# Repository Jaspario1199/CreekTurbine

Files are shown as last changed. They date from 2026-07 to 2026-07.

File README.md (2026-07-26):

# CreekTurbine 🌊⚡

A DIY **hydrokinetic** turbine you can drop into a creek — an "underwater wind
turbine" that harvests the *kinetic* energy of the moving stream to trickle-charge
a battery. No dam, no vertical drop, removable before floods.

> **Status: Mk1 DESIGN FROZEN — [docs/SPEC.md](docs/SPEC.md).** Every design
> decision is locked with rationale; the **complete unit is CAD-modeled** (14
> parametric parts + a positioned 28-part assembly, `cad/step/_assembly.step`);
> the physics engine (115 tests), verified rotor research, 19-finding red-team
> audit, and bench/field test protocol are all in. Next milestone: the wet
> prototype ([docs/TEST_PROTOCOL.md](docs/TEST_PROTOCOL.md)).

```bash
pip install -r requirements.txt
python -m scripts.measure_creek        # how to measure your creek (float method)
python -m scripts.size_turbine --figs  # size the turbine + render figures to ./output
python -m pytest                       # 46 checks on the physics
```

---

## Read this first: a creek is a *trickle-charger*, not a generator set

The power in moving water is `P = ½·ρ·A·v³`. That **v³** is the whole story:
double the water speed and you get **8×** the power. Two creeks that look the same
to your eye can differ 8× in what they'll make. So:

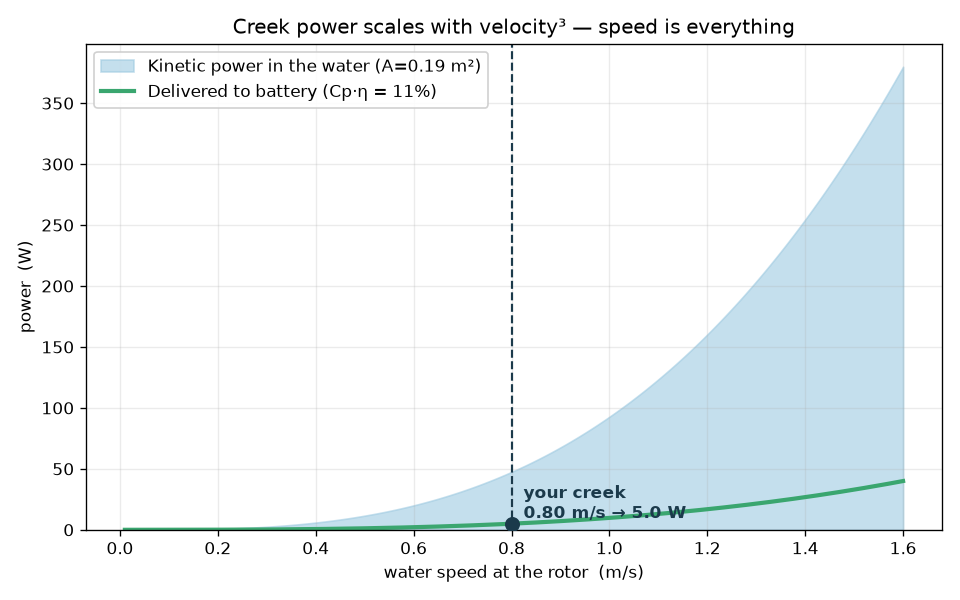
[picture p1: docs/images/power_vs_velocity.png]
Creek power scales with velocity cubed


- **Measure your creek's speed honestly** — it dominates everything else.
- A gentle 0.5 m/s creek yields a few watts; a brisk 1 m/s creek, tens of watts.
- **A few watts, 24/7, is genuinely useful.** 5 W around the clock ≈ **90 Wh/day**
  — enough to keep phones, trail/security cameras, LED lights, and IoT sensors
  alive indefinitely (a ~10 W always-on Wi-Fi router or a laptop needs a bit more
  creek). It is **not** going to run a fridge or a house.

The toolkit's job is to tell you the truth for *your* water before you spend a
dollar — and to show you the two free levers that beat buying bigger gear:
**measure the fastest spot**, and **speed the water up** with a chute or shroud
(since power ∝ v³, a 1.2× speed-up is a ~1.7× power gain).

---

## What it tells you (real output for the default creek)

`python -m scripts.size_turbine` on the placeholder creek (0.8 m/s, 1.5 m × 0.5 m
channel, 5 W target):

```
 TARGET: 5.0 W continuous at the battery
   → Savonius rotor: Ø 0.34 m × 0.54 m tall  (frontal area 0.19 m²)
   Blocks 25% of the wetted channel — comfortable.
   At 0.80 m/s: shaft ≈ 40 rpm, torque ≈ 2.0 N·m, mechanical ≈ 8.5 W → battery ≈ 5.0 W
 GENERATOR MATCH (the part people get wrong):
   Rotor turns ~40 rpm — that's SLOW. For a 12 V bus to cut in at your low-season
   ~0.48 m/s, pick a PMA with Ke ≈ 0.5 V/rpm (≈ 2 rpm/V).
 ENERGY: 5.0 W × 24 h × 75% uptime ≈ 90 Wh/day  (33 kWh/year)
 BATTERY: 19 Ah at 12 V (LiFePO4) for 2 days autonomy
 WHAT IT RUNS:  ✓ phone  ✓ security cam  ✓ LED light  ✓ sensors  ✗ Wi-Fi  ✗ laptop  ✗ fridge
```

It also renders these:

| Size vs. velocity | Daily energy budget | Recommended rotor |
|---|---|---|
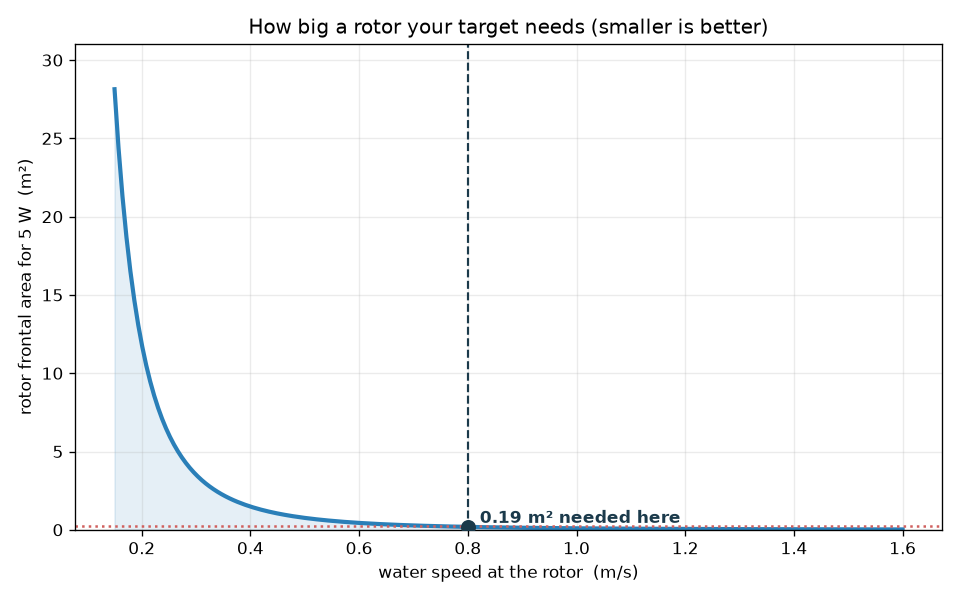
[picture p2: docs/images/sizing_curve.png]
sizing
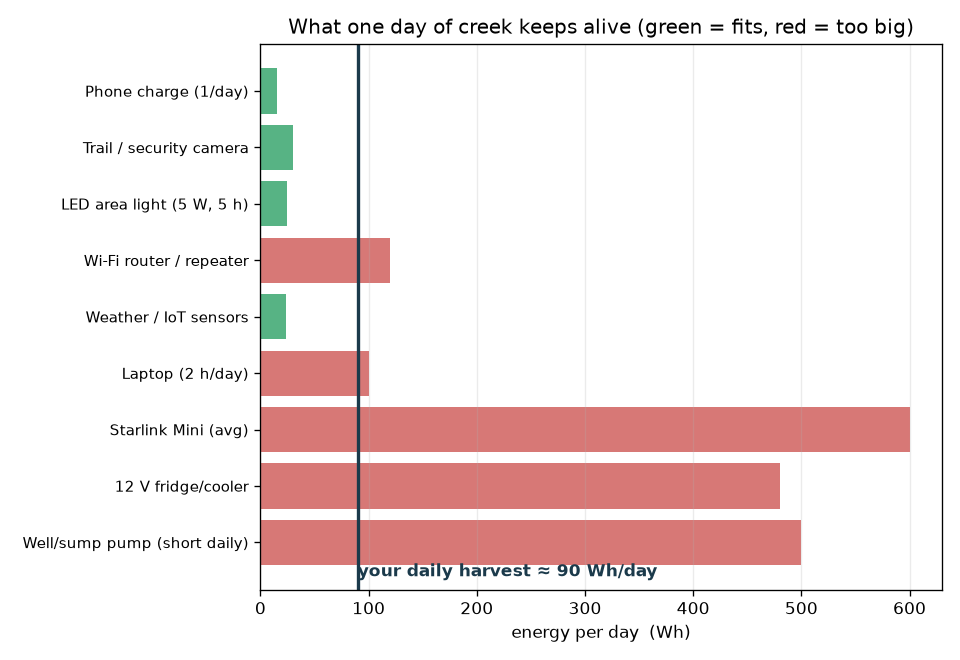
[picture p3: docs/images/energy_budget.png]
energy
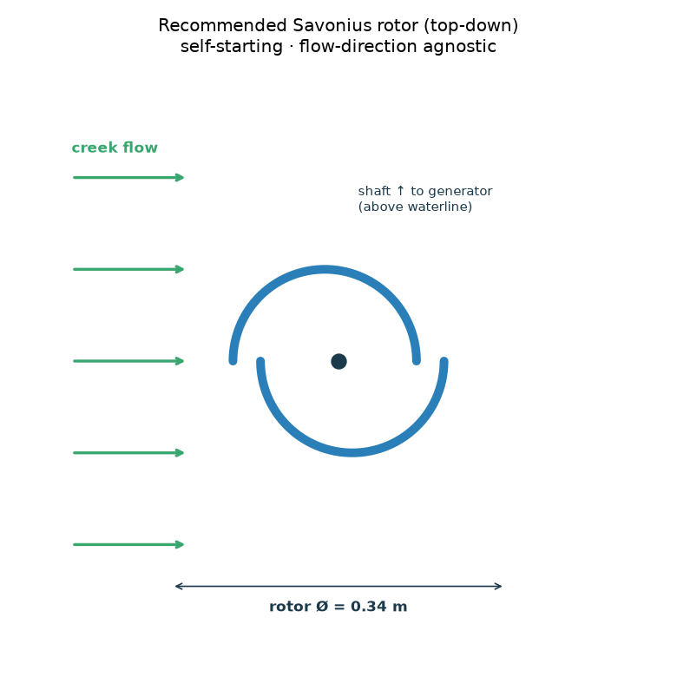
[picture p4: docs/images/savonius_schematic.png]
savonius
|  |  |  |

---

## Why a Savonius (vertical-axis) turbine

The default design is a **Savonius** — a vertical-axis drag rotor (think two
scoops making an S). Its power coefficient isn't the best (a propeller wins on
paper), but it's the best *system* for a real DIY creek:

- **Self-starts in slow water**, where a propeller just stalls.
- **Doesn't care which way the flow points** — creeks meander and eddy.
- **Vertical shaft ⇒ the generator sits on top, above the water.** This turns the
  single hardest problem — keeping a generator dry — into "bolt it to a plate in
  the air." Only the bearings get wet.
- **Debris-tolerant, low-rpm/high-torque, buildable from a barrel or PVC pipe.**

The costs — a bigger rotor per watt and a slow shaft that needs careful generator
matching — are shown explicitly, never hidden. Got a brisk, deep creek? Set
`TURBINE_TYPE = "axial"` and the model sizes the higher-efficiency propeller
instead. Details in **[docs/ARCHITECTURE.md](docs/ARCHITECTURE.md)**.

### Want an enclosed underwater box with a dry generator inside?

Yes — that's a *ducted turbine with a dry nacelle*, and it's modeled in
`ducted.py` / `scripts/box_turbine.py`. The honest punchline: a box around a
purely *kinetic* rotor gains little (a creek's speed is worth only ~3 cm of
head), **but building in a small elevation drop turns it into a low-head turbine
worth ~30× more** for the same opening. Cross the wet/dry wall with a **magnetic
coupling** (no shaft seal to leak), and mind that a submerged air box is very
buoyant. Full write-up: **[docs/BOX_AND_DUCT.md](docs/BOX_AND_DUCT.md)**.

### Want to carry it to any creek (camping / backyard)?

That's a **portable power station** — a sealed drop-in turbine, a *low-voltage DC*
cable to shore (never mains AC in the water), and a battery-buffered box on dry
land. The battery is the trick: loads run off it while the turbine tops it up, so
you get smooth, instant power and it works **24/7 — at night and in rain, unlike
solar**. A multi-input controller lets the same battery also charge from solar or
a wall outlet (your "switch between sources"). Modeled in `portable.py` /
`scripts/portable.py`; full write-up: **[docs/PORTABLE.md](docs/PORTABLE.md)**.

### Or fully self-contained — one box with a handle you set in the creek?

The cleanest form, and the vertical-axis design makes it natural: **one housing,
rotor at the bottom (wet), battery + generator + outlets stacked above the
waterline (dry), handle on top.** Set it in the stream and the outlets are live —
no cable, plug-and-play. The real catch is *stability* (a free-standing box in
current wants to slide/tip, so its base needs weight or a stake), which the model
sizes. Modeled in `selfcontained.py` / `scripts/self_contained.py`; full write-up:
**[docs/SELF_CONTAINED.md](docs/SELF_CONTAINED.md)**.

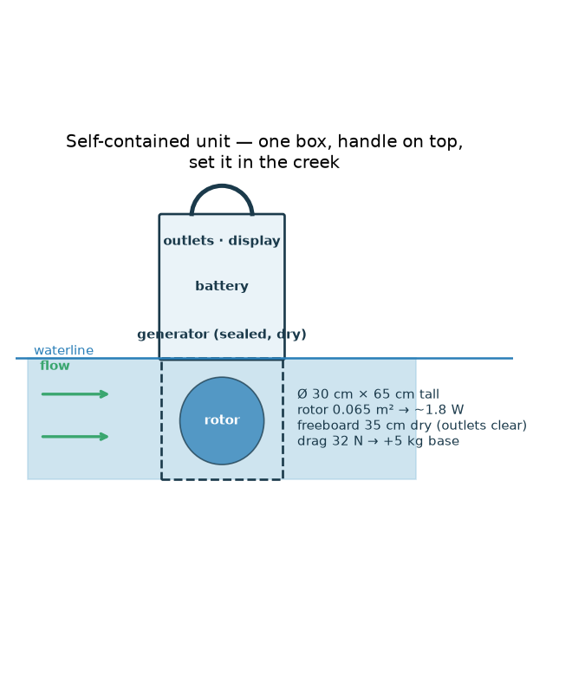
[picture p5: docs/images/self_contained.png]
Self-contained unit


### Want the highest-Cp rotor that still survives the creek?

A cited literature pass (**[docs/RESEARCH_ROTORS.md](docs/RESEARCH_ROTORS.md)**)
found the sweet spot: an **optimized/hydrofoil, helical Savonius**. Verified
results — a cambered-hydrofoil blade nearly **doubles Cp** (~0.26 vs ~0.13 at
0.4 m/s), and arc-angle/overlap/aspect + end-plate tuning reaches ~0.19 — while
keeping the blunt, self-starting, debris-shedding toughness a lift rotor throws
away. Selectable in `config.py` (`SAVONIUS_PROFILE = "conventional" | "optimized"
| "hydrofoil"`), and there's a printable **helical blade** in `cad/`.

---

## How it works (the modules)

1. **`hydrokinetics.py`** — the physics you must trust: `½·ρ·A·v³`, the Betz limit
   (16/27), rotor sizing, rpm/torque, flow-augmentation. Tested against
   hand-computed values.
2. **`rotor.py`** — Savonius & axial rotors behind one interface; turns a power
   target into rotor dimensions.
3. **`generator.py`** — the part people get wrong: **cut-in velocity** (below which
   you make *nothing*) and a Ke recommender to match your low-season flow.
4. **`energy.py`** — daily/annual Wh, battery Ah sizing, and the "what it runs" table.
5. **`siting.py`** — float-method + cross-section math to measure your creek.
6. **`simulator.py`** — renders all of it to PNGs (headless).
7. **`ducted.py`** — the "enclosed underwater air box" / ducted low-head turbine:
   flow-through-a-throat, the huge payoff of building in a little *head*, and how
   much ballast a submerged air box needs. See **[docs/BOX_AND_DUCT.md](docs/BOX_AND_DUCT.md)**.
8. **`portable.py`** — the carry-anywhere **power-station** build: battery-buffer
   runtime (sustained vs. burst), the waterproof low-voltage-DC cable to shore
   (volt-drop & gauge), and pack weight. See **[docs/PORTABLE.md](docs/PORTABLE.md)**.
9. **`selfcontained.py`** — the all-in-one "box with a handle": rotor-fits-box +
   freeboard geometry, and the drag/sliding/tipping math that sizes the base so
   the current can't move it. See **[docs/SELF_CONTAINED.md](docs/SELF_CONTAINED.md)**.

---

## Repository layout

```
creekturbine/
  config.py          # ← the ONLY file you edit: your creek, your goal, your battery
  hydrokinetics.py   # ½·ρ·A·v³, Betz, sizing, rpm/torque, augmentation
  rotor.py           # Savonius + axial rotor models (one interface)
  generator.py       # PMA cut-in velocity + Ke matching (the classic failure point)
  energy.py          # daily/annual energy, battery sizing, what-it-runs
  siting.py          # measure-your-creek math (float method, cross-section)
  ducted.py          # enclosed-box / ducted low-head turbine + buoyancy/ballast
  portable.py        # carry-anywhere power station: battery buffer, cable, weight
  selfcontained.py   # all-in-one "box with a handle": fit, freeboard, drag/tipping
  magnetics.py       # sealed magnetic coupling: torque model + sizing
  funnel.py          # converging-intake funnel: continuity + critical-velocity cap
  simulator.py       # renders the figures (matplotlib, headless)
scripts/
  measure_creek.py   # walk through measuring velocity & flow
  size_turbine.py    # end-to-end sizing report (+ --figs)
  box_turbine.py     # model the enclosed underwater air-box idea
  portable.py        # model the portable power-station build
  self_contained.py  # model the all-in-one box unit (+ --figs)
  mag_coupling.py    # size the sealed magnetic coupling to the rotor torque
  funnel.py          # model a converging chute for a mellow/shallow creek
  demo_sim.py        # render the whole picture book to ./output
cad/
  params.py          # ONE dimensional chain (mm): rotor -> plates -> housing -> skid
  parts/             # THE COMPLETE UNIT, 14 parametric parts: helical blade
                     #   (segmented printable), grooved end plates, mag-coupling
                     #   discs + magnet cover, bulkhead, cage rings, dry housing,
                     #   lid+handle, skid/ballast base, funnel wings, trash rack,
                     #   shaft coupler, generator mount
  export_all.py      # -> cad/step/*.step + cad/stl/*.stl (all 14)
tests/               # 46 checks on the physics/energy/generator/siting math
docs/
  ARCHITECTURE.md    # how the pieces fit + design decisions
  SITING.md          # measure first, then make the water faster (+ permits)
  BOX_AND_DUCT.md    # the enclosed underwater air-box idea, costed (dry generator + head)
  FUNNEL.md          # converging chute to make a mellow/shallow creek useful
  PORTABLE.md        # carry-anywhere power station (cable, battery, source-switching)
  SELF_CONTAINED.md  # all-in-one "box with a handle" set-in-the-creek unit
  RESEARCH_ROTORS.md # cited survey: high-Cp + durable rotor geometries (+ comparison table)
  MAG_COUPLING.md    # sealed magnetic coupling — the no-leak wet→dry crossing
  ASSEMBLY.md        # full build order stitching every part + subsystem together
  CRITIQUE.md        # the red-team audit: 19 findings, each fixed/documented/tracked
  TEST_PROTOCOL.md   # bench + field tests (B1–B5, F1–F4) that calibrate the model
  SAFETY.md          # water + electricity + a spinning rotor: read this
  HARDWARE.md        # BOM + the generator problem (cut-in, low rpm)
  ROADMAP.md         # phase-by-phase build plan
  RESEARCH.md        # the physics & why the default coefficients
```

---

## Where this is going

| Phase | What | Cost |
|---|---|---|
| **0** ✅ | Physics/sizing engine, rotor+generator+energy models, simulator, tests, CAD | Free |
| **1** | Measure your creek (2+ seasons), lock rotor size & generator Ke | ~$0 |
| **2** | Bench-build rotor + generator, prove **cut-in** and charging | 💰 generator + battery |
| **3** | Wet install: frame, anchoring, trash rack, **dump load**, sealed electronics | 💰 ~$250–450 |
| **4** | Flow augmentation (chute/shroud) + flood/winter survival | 💰 iteration |

The genuinely hard, risky parts are called out honestly: **matching a generator
to a slow shaft**, **keeping it dry and alive in a creek**, and the **legal/
environmental** rules you must settle *before* building. See
**[docs/ROADMAP.md](docs/ROADMAP.md)**.

**Ready to build?** [docs/ASSEMBLY.md](docs/ASSEMBLY.md) is the full,
phase-by-phase build order — plan in software → print/buy parts → rotor →
sealed drivetrain → dry electronics → housing/intake → bench test → wet install.
The **complete unit is CAD-modeled** (14 parametric parts on one dimensional
chain — see [cad/README.md](cad/README.md)):

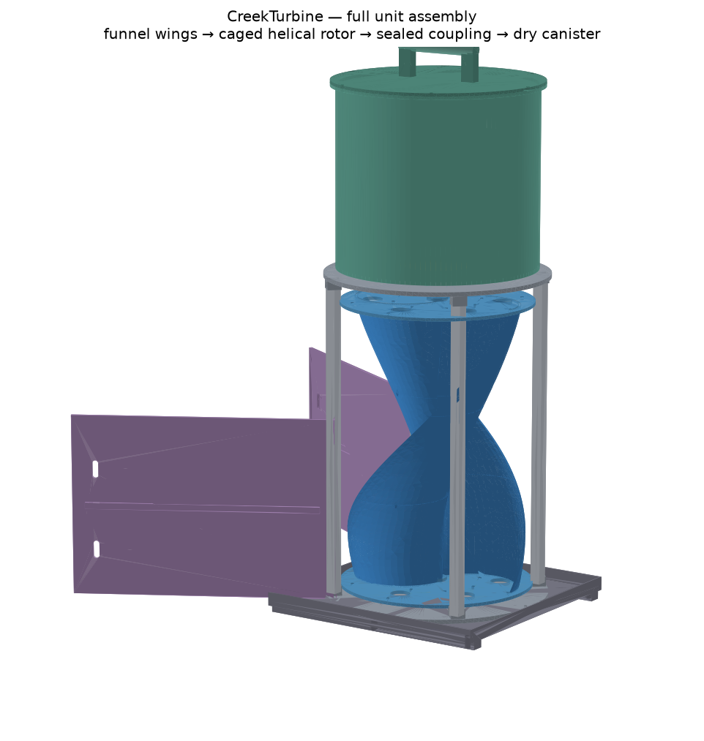
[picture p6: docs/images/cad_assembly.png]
Full unit assembly


> ⚠️ **Before you build, read [docs/SAFETY.md](docs/SAFETY.md).** A hydro source
> runs 24/7 and can't be switched off like a solar panel — it *needs* a charge
> controller with a dump load, a fused battery, and sealed, elevated electronics.
> And check your **water rights and fish-passage rules** first
> ([docs/SITING.md](docs/SITING.md)).

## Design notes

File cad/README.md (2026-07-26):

# CAD — the printed & cut structure

**The complete unit is modeled** — every physical piece of the machine, on one
parametric dimensional chain (blade → end plate → housing bore → cage → skid),
so changing `ROTOR_DIA`/`ROTOR_HEIGHT` re-derives everything:

Full unit assembly

**Base assembly model:** `python -m cad.assembly` exports the positioned 28-part
assembly — **`cad/step/_assembly.step`** (named parts; open in FreeCAD, Fusion,
Onshape, any STEP viewer) and `cad/stl/_assembly.stl` (single mesh). Bought
items (columns, shaft, generator, battery) are included as labeled solids.

The Savonius rotor's **scoops** are cut from cheap PVC pipe or sheet (not
printed). What's parametric here is the **structure that holds them and carries
the shaft up to the dry generator**:

| Part | What it is | Print notes |
|---|---|---|
| `end_plate` | Top & bottom discs with **profile-matched grooves** that seat the blade ends (a twisted edge can't take a bolt — it drops into its groove and is epoxied; bolt rings become clamping/through-rod holes). Print **2** identical; clock the top one to the blade twist at assembly. | PETG, 4+ walls, 40%+ infill. At Ø370 mm it exceeds most beds — **cut from HDPE sheet/plywood using the STEP as a template** for full-size rotors; print only small ones. Overhangs the scoops on purpose (raises Cp). |
| `savonius_blade` | Helical Savonius scoop — **one printable SEGMENT** (a full blade exceeds every consumer printer's Z). Print **`SCOOP_COUNT × BLADE_SEGMENTS`** copies (default 2×3); segments are identical — stack each rotated by `BLADE_SEG_TWIST`, register on 3 mm pins (filament) in the end-face holes, epoxy the joints. | PETG/ASA, 4+ walls; print upright. Twist = `BLADE_TWIST_DEG`; set 0 for straight. `BLADE_SEGMENTS` auto-computes from `PRINTER_MAX_Z`. |
| `shaft_coupler` | Joins the rotor shaft to the generator shaft; radial set screws. | Print solid-ish (PETG/ABS/nylon), or buy a metal coupler and use this as the fit reference. |
| `mag_coupling_disc` | Magnetic-coupling disc — ring of magnet pockets + shaft hub. Print **2** (wet + dry). Seals the wet→dry crossing with no shaft seal. | PETG; press magnets in alternating polarity. Seal/pot the wet disc's magnets. See [MAG_COUPLING.md](../docs/MAG_COUPLING.md). |
| `bulkhead` | The sealed wall the coupling drives through: thin center membrane + bolted, O-ring-grooved rim. | **Don't print it** — it's a flat disc: **cut from 3 mm PC/acrylic/FR4 sheet** using the STEP as a drill template. **NON-MAGNETIC only** — never plain steel. |
| `trash_rack` | Barred intake screen that sheds debris (the #1 field failure). Print **1+**. | PETG/ASA; angle it downstream-leaning. Size open area via `siting.screen_*`. |
| `generator_mount` | Top plate the PMA bolts to, standing above the waterline on legs. | PETG, 5+ walls. |
| `cage_ring_top` | Top of the open wet cage: sockets the 4 columns, carries the shared 8-bolt clamp circle (cage → bulkhead → housing floor in one stack). Print **1**. | PETG/ASA, 5+ walls. |
| `cage_ring_bottom` | Cage base disc: column sockets, raised lower-bearing boss (silt has to climb), drain holes, skid bolt circle. Print **1**. | PETG/ASA. Bearing seat = `BEARING_OD` flanged stainless. |
| *(cage columns)* | **BUY, don't print**: 4 × 20 mm aluminium square tube cut to `CAGE_COL_LEN` — stiffer and cheaper than any print, and a 600 mm part fits no bed. | Hacksaw + deburr; clamp screws hold them. |
| `housing_upper` | The dry canister: sealed floor (bulkhead clamps under it), shell, lid flange, outlet-panel cutout. Print in sections **or roll from HDPE/PVC pipe** (STEP = cut/drill template). | Ø384 — pipe/sheet at full size. |
| `lid_handle` | Gasketed lid + the carry handle (takes the unit's full weight — thick bar, wide posts). Print **1**. | PETG/ASA, high infill in the posts. |
| `skid_base` | Skid + ballast tray: sacrificial runners underneath (cut from UHMW ideally), perimeter ballast tray, cage bolts, corner stake + tether holes. | Runners = replaceable wear parts. |
| `funnel_wing` | Converging-intake wing wall (make **2**, one flipped): mounting flange to a cage column, mid-height rib, stake slots. | **Cut from 6 mm HDPE sheet** at full size (STEP = template); print for small units. |
| `magnet_cover` | Thin bonded cover disc sealing the WET coupling disc's potted magnets — the marine barrier, not a glue dab. Print **1** (or cut from 1 mm PC). | Bond in wet epoxy over the potted face. |

Load-bearing, permanently-wet parts — the **shaft, fasteners, bearings** — are
**metal (stainless)**, never printed.

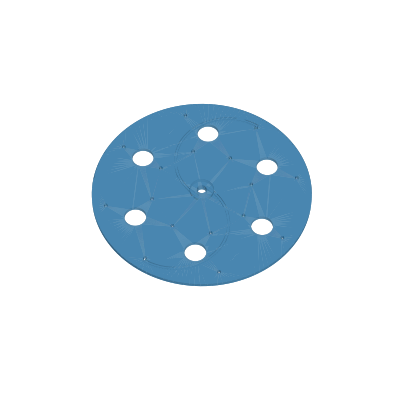
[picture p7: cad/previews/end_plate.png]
end plate
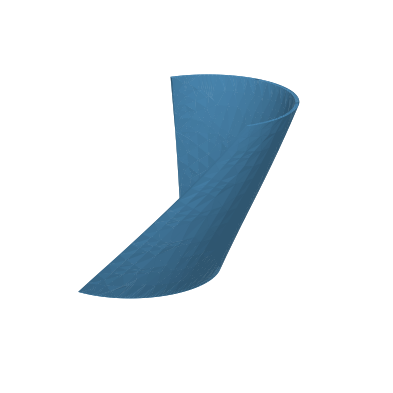
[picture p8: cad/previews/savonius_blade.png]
helical blade
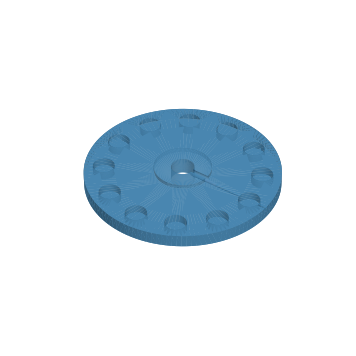
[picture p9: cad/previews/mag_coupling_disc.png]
mag coupling disc
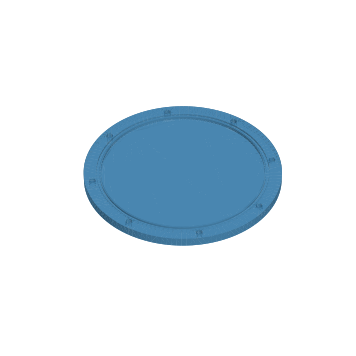
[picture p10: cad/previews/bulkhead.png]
bulkhead
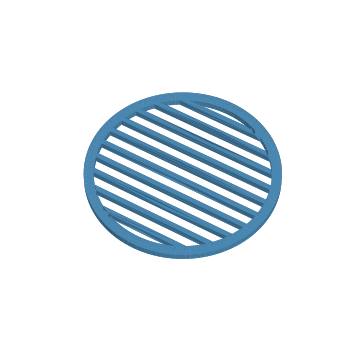
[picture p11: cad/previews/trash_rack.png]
trash rack
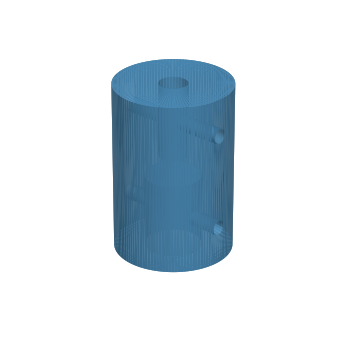
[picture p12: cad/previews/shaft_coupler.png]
shaft coupler
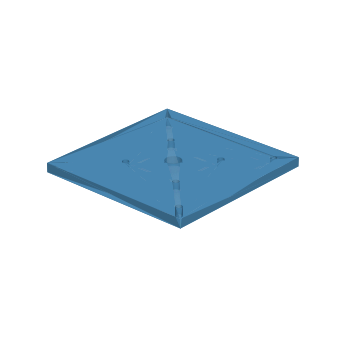
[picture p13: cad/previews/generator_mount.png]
generator mount
      

## Regenerating

```bash
pip install -r requirements-cad.txt        # heavy: pulls OpenCascade
# 1. edit cad/params.py — especially SHAFT_DIA, GEN_SHAFT_DIA, GEN_BODY_DIA,
#    GEN_BOLT_CIRCLE to match the parts you actually buy, and ROTOR_DIA /
#    ROTOR_HEIGHT to match `python -m scripts.size_turbine`
python -m cad.export_all                   # writes cad/step/*.step + cad/stl/*.stl
```

The committed STEP/STL match the defaults in `cad/params.py` (which mirror the
recommended rotor from the default `config.py`). **Always sanity-check the mesh
in your slicer before printing** — the bolt patterns are a sensible starting
point, not a guarantee they line up with your specific scoop pipe.

## Printing for water

- **PETG** is the sweet spot: cheap, tough, low water absorption, UV-OK for a
  season. **ASA/ABS** if you want better UV life. Avoid bare **PLA** underwater
  — it creeps and slowly hydrolyzes.
- Print **watertight**: 4–6 perimeters, 30–50% infill, and consider a wipe of
  epoxy on the end plates for a multi-season part.
- Anything structural underwater should really be **metal**; treat printed parts
  as brackets and jigs, not the primary wet load path.

### Scuff- / abrasion-resistant outer shell

The housing drags on gravel and takes rock knocks, so the **outer** wants to be
tougher than a printed wall:

- **Best: HDPE or UHMW-PE** — a cut plastic barrel, sheet, or machined block. It's
  what kayaks and cutting boards are made of: extremely scuff/abrasion resistant,
  tough, near-zero water absorption. (Trade-off: hard to 3D-print or glue — bolt
  and gasket it instead.)
- **Printed alternative: ASA** (UV + impact) or **PCTG / PETG-CF**, with a thick
  wall — then add a rugged skin: a **truck bed-liner coating** (e.g. roll-on
  polyurethane) sprayed over the shell resists scuffs well.
- **Sacrificial bottom skid + corner bumpers:** a bolt-on **UHMW skid plate** on
  the base and **TPU bumpers** on the corners take the abuse and are cheap to
  replace. This is the highest-value scuff protection for the least effort.

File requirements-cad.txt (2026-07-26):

# CAD: regenerate the printed parts (STEP/STL) from the parametric scripts.
# Heavier install (pulls OpenCascade via cadquery-ocp). Only needed if you edit
# cad/params.py and want to re-export.
cadquery>=2.4

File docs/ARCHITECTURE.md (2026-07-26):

# Architecture — how the pieces fit

CreekTurbine is a small, honest engineering toolkit. Everything is driven from
**one file you edit** (`creekturbine/config.py`) and computed from there, so you
can answer "is this worth building for MY creek?" before spending a dollar.

## The energy chain (and where power is lost)

```
  creek flow                                                    your loads
  (v, depth) ──► ROTOR ──► SHAFT ──► GENERATOR ──► RECTIFIER ──► CHARGE ──► BATTERY ──► USB / 12V
                 (Cp)      (bearings) (PMA, η)     (3-phase)     CONTROLLER   (store)     / inverter
                  │          │          │                          │
             capture at    torque    volts ∝ rpm               MPPT/PWM +
             most Betz     & rpm      (cut-in!)                 DUMP LOAD
             (16/27)                                           (overspeed safety)
```

Each stage is a module:

| Stage | Module | The one thing it tells you |
|---|---|---|
| Resource | `hydrokinetics.py` | how much power is in the water (`½·ρ·A·v³`) and the Betz ceiling |
| Rotor | `rotor.py` | Savonius vs axial geometry, Cp, and the rotor **size** to hit a target |
| Shaft | `hydrokinetics.py` | rpm & torque from velocity + TSR (this is what the generator sees) |
| Generator | `generator.py` | the **cut-in velocity** below which you make nothing, and how to match Ke |
| Storage | `energy.py` | daily/annual Wh, battery Ah, and **what it actually runs** |
| Siting | `siting.py` | how to *measure* v and A honestly (float method, cross-section) |
| Picture | `simulator.py` | renders all of the above to PNGs |

## Design decisions (and why)

**Hydrokinetic, not "dam-and-drop."** A creek is a low-head, flowing resource.
Building a dam to make head is a permitting/ecological nightmare and usually
illegal on a natural creek. We harvest the *kinetic* energy of the moving
water — an "underwater wind turbine." No dam, removable, low impact.

**Vertical-axis Savonius is the default.** Not because its Cp is best (it
isn't — a propeller wins there), but because it's the best *system* for a DIY
creek:

- **Self-starting in slow water** (drag-driven), where a propeller stalls.
- **Flow-direction agnostic** — creeks meander and back-eddy; it doesn't care.
- **Vertical shaft ⇒ the generator lives on top, above the water.** This turns
  the single hardest problem (keeping a generator dry) into "bolt it to a plate
  in the air." Only bearings get wet.
- **Low rpm, high torque, debris-tolerant, buildable from a barrel/PVC.**

The cost is a bigger rotor for the same watts, and a low shaft rpm that forces
careful generator matching. The toolkit makes both costs explicit instead of
hiding them. If your creek is genuinely brisk and deep, `TURBINE_TYPE = "axial"`
models the higher-Cp propeller alternative.

**Cut-in is a first-class citizen.** The most common DIY failure is a generator
that never reaches charging voltage at creek rpm. `generator.py` computes the
cut-in *velocity* and recommends a Ke so it lands at your creek's **low-season**
flow, not its average.

**One interface for both rotors.** `SavoniusRotor` and `AxialRotor` share the
same `_RotorBase` surface (`frontal_area`, `performance()`, `electrical_power()`),
so everything downstream — sizing, generator matching, energy, the simulator —
works unchanged when you switch types. (Same "one interface, swappable
implementations" trick a good perception stack uses for its detectors.)

## Coordinate & unit conventions

Pure SI throughout the Python (`m`, `m/s`, `W`, `Wh`, `kg`, `rad`); the CAD is
in millimeters (parametric, `cad/params.py`). No hidden globals — every function
takes what it needs and returns a number or a dataclass, which is why the whole
thing is trivially testable (`tests/`, 46 checks against hand-computed values).

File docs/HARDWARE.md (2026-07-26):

# Hardware — bill of materials & the generator problem

Prices are rough 2026 USD for a small (~5–20 W) creek build and will vary. Run
`python -m scripts.size_turbine` first — it tells you the rotor size, the shaft
rpm, and the generator Ke to shop for.

## The one hard part: the generator

Everything else is plumbing; the generator is where builds live or die, for two
reasons the toolkit makes explicit:

1. **Low rpm.** A Savonius turns *tens* of rpm. Most cheap motors are wound to
   make their rated voltage at *thousands* of rpm, so used bare they never
   "cut in" (reach charging voltage) in a creek.
2. **Cut-in.** Below the rpm where the rectified voltage exceeds your battery,
   **zero** current flows. `generator.py` computes the cut-in *velocity*; aim it
   at your creek's **low-season** flow.

Three ways to solve it, cheapest first:

| Option | What | Trade-off |
|---|---|---|
| **Low-Kv PMA** (recommended) | A purpose-made low-rpm permanent-magnet alternator / "PMA" / axial-flux generator (the kind sold for small wind turbines, e.g. rated ~12 V at a few hundred rpm). | Cleanest match; direct-drive a Savonius via the coupler. Costs more than a scrap motor. |
| **Step-up drive** | A common motor + a belt/gear step-up (the report prints the ratio, often ~5–15:1). | Uses cheap parts; adds friction, noise, a wear item, and a few % loss. |
| **Repurposed motor** | A brushed DC motor, a stepper (rectified), a car alternator (no — needs field current & high rpm), or a hoverboard/e-bike hub motor (good: many poles, low Kv). | Free-ish; you must measure its Ke and check cut-in. Hub motors are the best scrap option. |

**Rectifier:** a PMA is 3-phase AC — add a **3-phase bridge rectifier** (six
diodes / a module) to make DC. A brushed DC motor needs only a single diode to
block back-feed.

## Bill of materials

### Rotor & structure
| Item | Notes | ~USD |
|---|---|-----:|
| PVC pipe or HDPE drum for scoops | e.g. a 200 mm PVC pipe cut lengthwise = two scoops; or half a plastic barrel | 10–30 |
| 3D-printed end plates ×2, coupler, gen mount | PETG; print from `cad/` (or cut plywood/HDPE plates) | filament you have |
| **Stainless shaft** (e.g. 16 mm) | permanently wet — must be stainless | 15–30 |
| **Marine/stainless bearings** ×2 (pillow-block) | top can be a plain bearing; keep above silt | 15–35 |
| Stainless bolts/nuts/washers (M5/M6/M8) | scoops, plates, frame | 15–25 |

### Frame & siting
| Item | Notes | ~USD |
|---|---|-----:|
| Frame (galv/stainless unistrut, EMT, or treated lumber) | must survive a flood; make it liftable | 25–60 |
| Anchoring (rebar stakes, ground anchors, sandbags) | to bed AND bank | 15–40 |
| Trash rack / intake screen | angled mesh upstream of the rotor | 10–25 |

### Electrical
| Item | Notes | ~USD |
|---|---|-----:|
| **Low-Kv PMA / hub motor generator** | the heart. REALITY CHECK: buyable PMAs top out ~0.10–0.15 V/rpm — if the report recommends more, use a **boost MPPT** (below) or a belt step-up; don't shop for a unicorn | 40–150 |
| 3-phase bridge rectifier (or Schottky diodes) | AC → DC | 8–20 |
| **BOOST-type MPPT charge controller w/ dump load** | steps a few volts of slow-PMA output UP to the battery — the modern fix for slow-rotor cut-in. Spec **low quiescent draw (<10 mA)**: a 25 mA idler eats 15 %+ of a small harvest, 24/7 | 30–100 |
| **Dump/diversion resistor or heating element** | soaks up power when the battery is full — wired **generator-side, before the BMS** (see SAFETY) | 10–25 |
| **LiFePO4 battery** (12 V, sized by the report, e.g. 20–50 Ah) | BMS **must include low-temperature charge cutoff** (LiFePO4 won't take charge below 0 °C) | 60–180 |
| **Thrust / angular-contact bearings** (pair) | the magnetic coupling's discs pull together with ~300–400 N constantly — plain radial bearings grind flat | 10–30 |
| **12 V → USB-C PD buck module (45–65 W)** | what actually charges the laptop from the battery | 12–30 |
| **Main fuse + holder** at the battery + terminal | the most important safety part | 5–15 |
| Marine tinned wire, gel/heatshrink connectors, sealed enclosure | corrosion is relentless near water | 25–60 |
| (optional) 12 V→USB / small pure-sine inverter | to actually use the power | 15–60 |

**Ballpark:** a minimal ~5–10 W trickle-charger lands around **$250–450**; add
$100–200 for a bigger battery, a nicer MPPT controller, and an inverter.

## Portable ("camping") variant

For a carry-anywhere unit (see [PORTABLE.md](PORTABLE.md)), swap the fixed frame
for a lighter kit and add:

| Item | Notes | ~USD |
|---|---|-----:|
| Compact sealed generator + **magnetic coupling** | no shaft seal to leak; drop-in-any-creek. Magnets: ~24 × Ø15×6 mm N42 NdFeB (two discs) + a thin non-magnetic bulkhead. Size with `scripts.mag_coupling`; see [MAG_COUPLING.md](MAG_COUPLING.md) | 50–120 |
| **Marine tinned DC cable** + **IP68 potted connectors** | the "waterproof extension cord" — low-voltage DC only | 20–60 |
| Portable **LiFePO4 pack** (e.g. 300–500 Wh) | the buffer that gives smooth, instant, 24/7 power | 150–350 |
| **Multi-input charge controller** (turbine + solar + USB-C) | your "switch between sources" | 30–90 |
| Fast anchor kit (stake + guy line / sandbags) | deploy in minutes | 15–35 |
| **Scuff-resistant outer**: HDPE/UHMW shell (or ASA + bed-liner coat) + **UHMW skid plate** + **TPU corner bumpers** | takes gravel drag and rock knocks; skid/bumpers are cheap sacrificial wear parts | 20–70 |

Use a **higher bus voltage (24–48 V)** for anything but the shortest cable run —
it slashes the copper needed and the volt-drop (the model shows ~16× less copper
going 12 V → 48 V). Keep any 120/230 V AC inverter **on land, after the battery**.

## What NOT to do
- **No car alternator** for direct creek drive — it needs field excitation and
  thousands of rpm; it won't cut in.
- **No bare PLA** underwater — it creeps and hydrolyzes. PETG/ASA or metal.
- **Never** run the turbine with no electrical load and no dump — it free-spins
  and destroys itself (and spikes the electronics). See [SAFETY.md](SAFETY.md).

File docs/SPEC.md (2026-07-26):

# CreekTurbine Mk1 — frozen design specification

**Status: DESIGN FROZEN** (rev 1). Every decision below is locked with its
rationale; the short list of parameters *deliberately* left to prototype
calibration is at the end. The complete unit is modeled — open
**`cad/step/_assembly.step`** in any CAD tool for the base model, or regenerate
everything from `cad/params.py` (one dimensional chain).

Full unit assembly

## Identity & envelope

| | |
|---|---|
| Concept | Self-contained hydrokinetic creek turbine — "a box with a handle you set in the stream" |
| Deploys in | any creek **≥ 4 ft wide**, **6 in – 3 ft deep**, mellow flow (~0.4 m/s+) |
| Footprint | skid 460 × 460 mm; funnel wings gather a ~0.9 m swath |
| Height | ~1.02 m (skid → handle) |
| Carry weight | **~15 kg (33 lb) dry** — under the 40 lb budget; ballast is **creek rocks added on-site** into the skid tray, so you never carry it |
| Output | 12 V LiFePO₄ buffer → USB-C PD (laptop), USB, 12 V |
| Performance | ~1.7–4 W continuous (mellow creek, universal funnel): **~1 laptop charge/day in ≥1 ft of water**, derating to ~0.4/day at 6 in. Brisker water or site wing-walls raise it substantially (v³) |

## Frozen decisions (the design record)

| # | Decision | Frozen choice | Why (full rationale linked) |
|---|---|---|---|
| D1 | Energy principle | **Hydrokinetic** (no dam) | legal/eco footprint, removable — [ARCHITECTURE](ARCHITECTURE.md) |
| D2 | Rotor type | **Vertical-axis Savonius** | self-starts in slow water, direction-agnostic, debris-tolerant, vertical shaft puts the generator above water — [RESEARCH_ROTORS](RESEARCH_ROTORS.md) |
| D3 | Blade geometry | **Helical (180° twist), arc-optimized scoop, overlap 0.15, aspect ~1.6, end plates** | verified Cp levers; helix adds self-start smoothness + debris shedding — [RESEARCH_ROTORS](RESEARCH_ROTORS.md) |
| D4 | Sizing basis | **Cp 0.18 (conservative)** for all sizing; optimized geometry's 0.19–0.25 is *margin*, not promise | lab-vs-field honesty — [CRITIQUE #16](CRITIQUE.md) |
| D5 | Rotor size | **Ø 340 × 540 mm** (3 printed segments/blade × 2 blades) | 5 W target at 0.8 m/s; segments fit a 240 mm printer Z — [CRITIQUE #3](CRITIQUE.md) |
| D6 | Blade↔plate joint | **Profile-matched grooves** in the end plates + through-rod clamps + epoxy | a twisted edge can't take a bolt; shared profile source `cad/lib.py` — [CRITIQUE #4](CRITIQUE.md) |
| D7 | Intake | **Universal free-standing funnel**, 0.9 m gather mouth, 0.35 m tall wings | works in any ≥4 ft creek without bank works; speed-up capped honestly at √(g·y) — [FUNNEL](FUNNEL.md) |
| D8 | Wet→dry crossing | **Axial magnetic coupling** (12 × Ø15×6 N42 per disc, R55, 3 mm gap → ~4.2 N·m, slips on overload) through a **cut-from-sheet non-magnetic bulkhead** | no shaft seal to leak; built-in torque limiter — [MAG_COUPLING](MAG_COUPLING.md) |
| D9 | Coupling thrust | **Thrust/angular-contact bearings both shafts** (≥570 N) | ~380 N constant axial pull — [CRITIQUE #2](CRITIQUE.md) |
| D10 | Generator + charge path | Low-Kv PMA → 3-phase rectifier → **boost-MPPT** (low quiescent <10 mA) → 12 V LiFePO₄ (BMS w/ low-temp cutoff) | the *buyable* fix for slow-rotor cut-in — [CRITIQUE #1](CRITIQUE.md) |
| D11 | Overspeed safety | **Dump/clamp on the generator side, before the BMS** + fuse at battery + | BMS disconnect must never orphan the PMA — [SAFETY](SAFETY.md), [CRITIQUE #9](CRITIQUE.md) |
| D12 | Bus voltage | **12 V** | no shore cable in the self-contained form; richest USB/12 V ecosystem ([PORTABLE](PORTABLE.md) covers the 24–48 V cable variant) |
| D13 | Structure | Printed rings/plates (PETG/ASA) + **bought 20 mm Al tube columns** + stainless Ø16 shaft, Ø22 flanged bearings | print what's complex, buy what's long/structural — [cad/README](../cad/README.md) |
| D14 | Outer durability | **HDPE/UHMW shell** (or ASA + bed-liner), **sacrificial UHMW skid runners**, TPU bumpers | scuff resistance with cheap replaceable wear parts |
| D15 | Debris strategy | Blunt drag rotor + **angled trash rack** + open cage + drain holes + raised bearing boss | debris is the #1 field failure — [RESEARCH_ROTORS §4](RESEARCH_ROTORS.md) |
| D16 | Flood strategy | **Retrieval line + pull before storms**; stakes/ballast as backstop (~670 N flood drag computed) | you don't out-anchor a flood — [CRITIQUE #5](CRITIQUE.md) |
| D17 | Loads philosophy | Battery-buffered: loads always run off the pack; turbine trickles it back | smooth output, burst capability, source-agnostic charging |

## Key interfaces (for anyone extending the CAD)

- **Main clamp stack:** cage top ring → bulkhead → housing floor, **8 × M5 on Ø161** — one bolt circle seals and structures the wet/dry joint
- **Shaft:** Ø16 stainless; lower bearing Ø22 flanged in the cage boss; coupling discs bore Ø16 w/ M5 set screws
- **Cage columns:** 4 × 20 mm square tube, 604 mm, socketed ±15 mm with radial M5 clamps
- **Skid bolts:** 4 × M5 on Ø406; stake holes Ø10 at corners
- **Lid:** 6 × M5 on Ø394, gasketed, lip-registered

## Deliberately NOT frozen (calibrate on the prototype — [TEST_PROTOCOL](TEST_PROTOCOL.md))

| Parameter | Current assumption | Calibrated by |
|---|---|---|
| Funnel `confinement` | 0.82 | **F2** float test through the throat |
| Real rotor Cp | 0.18 sizing / 0.19–0.25 geometry | **F3** logged watts |
| Generator Ke & cut-in | catalog value | **B1** drill test |
| Coupling slip torque | ~4.2 N·m (τ·A·R model) | **B2** lever + scale |
| Maintenance interval | unknown | **F4** 72 h soak |

## Cost & verification

- **BOM band:** ~$300–480 ([HARDWARE](HARDWARE.md)) + ~2 kg filament
- **Software verification:** 115 physics/model tests passing; 14 parts + assembly export clean; 19-finding red-team audit closed ([CRITIQUE](CRITIQUE.md))
- **Research basis:** 22 adversarially-verified literature claims ([RESEARCH_ROTORS](RESEARCH_ROTORS.md))

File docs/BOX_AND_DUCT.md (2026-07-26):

# The enclosed underwater box (ducted / low-head turbine)

> "Can I have an enclosed, mostly air-filled box underwater — dry inside — that
> lets water flow in through one part, past a turbine, and out?"

**Yes.** You've described a *ducted turbine with a dry nacelle*, which is how a
lot of real hydro gear is built. This page makes the idea quantitative. Model it
for your creek with:

```bash
python -m scripts.box_turbine --static-head 0.3 --throat 0.05 --air-volume 0.08
```

## The two things a box buys you

1. **A dry generator.** Routing water through only a defined channel lets the
   generator and electronics live in the air-filled part. Keeping the generator
   dry is the single hardest problem in the whole project, so this is a real win.
2. **Flow control / augmentation.** A shaped inlet nozzle + flared outlet
   (diffuser) can pull more flow through the turbine than a bare rotor of the
   same size — the "shrouded / diffuser-augmented" turbine, worth roughly
   1.3–2.5× for a good one. That's the `--diffuser` knob.

## The catch, and the thing that makes it actually worth it

A creek's **speed is worth almost no head**: `v²/2g` is only ~3.3 cm at 0.8 m/s.
So a box wrapped around a purely *kinetic* rotor gains little on its own — the
model shows ~4 W for a 0.05 m² throat at 0.8 m/s.

The unlock is **building in a real elevation drop** (head, `H`). Put the inlet a
little higher/upstream and the outlet lower, and you become a **low-head
turbine**, where power is `P = ρ·g·Q·H·η`. The numbers jump:

| Box (0.05 m² throat, 0.8 m/s creek) | Throat speed | Flow | ~Electrical |
|---|---|---|---|
| Purely kinetic (0 m drop) | 0.68 m/s | 34 L/s | ~4 W |
| **With a 0.30 m built-in drop** | 2.17 m/s | 109 L/s | **~140 W** |

A modest drop is worth **~30×** the kinetic-only box for the same opening. Head,
not velocity, is where a creek gives real power.

**But be honest about what "building in a drop" means.** You get head by
*diverting* water from an upstream point to a lower outlet (classic micro-hydro),
or by pooling it behind a small weir. That is a bigger intervention than a
drop-in kinetic rotor and carries real consequences:

- You need enough natural **slope** to find 0.2–0.5 m of drop over a sensible
  distance (many creeks have it; measure with a level and a stick).
- Diverting/pooling flow has **stronger permit and fish-passage implications**
  than a hydrokinetic rotor — see [SITING.md](SITING.md#4-permits--neighbors-do-this-before-you-build).
  Keep it small, keep it removable, keep a path for water and wildlife.
- More power means a **bigger battery, a real dump load, and heavier wiring** —
  re-read [SAFETY.md](SAFETY.md).

## Crossing the wet/dry wall — use a magnetic coupling

The turbine is wet; the generator is dry; something must connect them through the
box wall. Two ways:

- **Shaft seal** (lip/mechanical seal): cheap, but a wear item and the #1 leak
  point on any submerged machine.
- **Magnetic coupling** (recommended): the wet rotor carries magnets that drive a
  matching magnet set on the dry generator shaft *through* a solid, unbroken wall.
  **No penetration, nothing to seal, nothing to leak.** For a DIY box this is the
  elegant answer; size it for the torque from `scripts.size_turbine`.

## If you fully submerge it: buoyancy is the enemy

An air-filled box wants to **float, hard**. Even a small ~0.08 m³ air pocket lifts
with ~785 N (~80 kg). To sink and hold a submerged box you need serious ballast
(the model: ~180 kg of concrete for that case, with a safety factor), plus:

- A **vent/snorkel to the surface** — a sealed air pocket slowly dissolves into
  the water and the box floods over weeks.
- Anchoring to **bed and bank** against currents trying to lift/roll it.

**Simpler recommendation:** unless you need it hidden or the creek is deep, don't
fully submerge an air box. Keep the **dry generator housing at/above the water
surface** and duct the water through/under it. You get every benefit (dry
generator, ducted flow, optional head) without the buoyancy and air-loss
headaches.

## This changes the turbine you'd want

The Savonius wins in *open* water. Once flow is confined in a duct, its perks
(self-start, direction-agnostic) stop mattering and you'd switch to a higher-
efficiency type that suits a channel:

- a **ducted axial propeller** (the duct fixes its weaknesses), or
- a **crossflow / Banki turbine** — water enters, crosses the blades twice, and
  exits: simple to build, debris-tolerant, and a natural fit for a "water enters
  here, leaves there" box. If you go the small-head route, this is the pick.

## What's modeled here

`creekturbine/ducted.py` (tested in `tests/test_ducted.py`):

- `velocity_head(v)` — why a creek's speed is worth so little head
- `low_head_power(Q, H, η)` — the micro-hydro bedrock equation
- `throat_velocity(H, Cd)` — head → flow through the throat (Torricelli + losses)
- `DuctedBox` — a box with throat area, static head, diffuser gain → flow & power
- `buoyancy_force_n()` / `ballast_mass_kg()` — how much ballast a submerged air box needs

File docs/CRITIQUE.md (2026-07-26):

# Design critique — the red-team audit and what was done about it

A deliberate attempt to break the design across manufacturability, flooding,
power, and field-survival, with every finding tracked to a resolution. Statuses:
**FIXED-IN-CODE** (model/CAD now handles it), **DOCUMENTED** (procedure/spec
change), **ACCEPTED** (known limit, stated honestly), **OPEN** (needs field data).

## 🔴 Critical — would have stopped the build working

| # | Finding | Resolution |
|---|---|---|
| 1 | **Recommended generator Ke was unbuyable.** The report asked for 0.3–1.0 V/rpm PMAs; the market tops out ~0.10–0.15 V/rpm. Direct-drive at 40 rpm on a 12 V bus was a fantasy — the classic dead-on-arrival DIY mistake. | **FIXED-IN-CODE** — `generator.practical_options()` reality-checks the Ke; `size_turbine` now prints **Fix A: boost-type MPPT** (charges 12 V from a few volts of PMA output, cut-in no longer needs to beat battery voltage) or **Fix B: ~4:1 belt step-up** onto a realistic 0.12 V/rpm PMA. BOM updated. |
| 2 | **Magnetic coupling axial pull unmodeled.** The discs don't just make torque — they attract with ~**380 N (~39 kg), constantly**. On plain radial bearings that grinds the drivetrain flat. | **FIXED-IN-CODE** — `AxialMagCoupling.axial_force_n()`; `mag_coupling` prints the pull and the required **thrust/angular-contact bearing** rating. [MAG_COUPLING.md](MAG_COUPLING.md) updated. |
| 3 | **Helical blade was unprintable** (540 mm tall vs ~240 mm printer Z). | **FIXED-IN-CODE** — blade now exports as **one stackable segment** (`BLADE_SEGMENTS` auto-computed from `PRINTER_MAX_Z`; segments of a helix are identical, so one STL → print `SCOOP_COUNT × BLADE_SEGMENTS` copies), registered on 3 mm pins through end-face holes, epoxied. |
| 4 | **Blade-to-plate attachment didn't exist** — a twisted blade edge can't take a vertical bolt; the bolt rings were decorative for a helical blade. | **FIXED-IN-CODE** — end plates now cut **profile-matched seating grooves** from the *same* cross-section definition the blade extrudes (`cad/lib.py`, single source of truth). Blade ends drop in, epoxy + through-rods clamp. Plates stay identical parts (grooves are SCOOP_COUNT-fold symmetric; clock the top plate to the twist at assembly). |

## 🟠 Serious — wrong numbers or predictable field failures

| # | Finding | Resolution |
|---|---|---|
| 5 | **Flood loading never checked** — stability used *operating* velocity; a 2.5 m/s storm pushes ~**670 N (~10×** operating). | **FIXED-IN-CODE** — `flood_drag_n()` / `flood_anchor_force_n()`; `self_contained` prints the flood case and the honest advice: **retrieval line, pull before storms**. |
| 6 | **Charge-controller idle draw ignored** — a typical MPPT idles ~0.25 W, 24/7, dry creek included; that's 15 %+ of a small harvest. | **FIXED-IN-CODE** — `energy.net_daily_energy_wh()` (can go **negative**, and warns); `CONTROLLER_IDLE_W` in config; report shows net. BOM: spec **low-quiescent (<10 mA)** controllers. |
| 7 | **Funnel `confinement = 0.82` is an invented number** — no literature covers a free-standing intake's realized speed-up. | **DOCUMENTED + OPEN** — flagged as an engineering assumption in code + [FUNNEL.md](FUNNEL.md); field-calibrate by floating a stick through the throat. Absolute watts carry this uncertainty. |
| 8 | **Universal funnel gathered the full water column** even in 3 ft water, though the intake mouth is ~0.35 m tall. | **FIXED-IN-CODE** — `universal()` caps gathered depth at `intake_height`. (Choke already capped the output, so published numbers stand.) |
| 9 | **BMS disconnect defeats the dump load** — battery full/cold → BMS opens → PMA open-circuits and overspeeds *despite* a "correctly wired" dump. | **DOCUMENTED** — wire the dump/clamp **on the generator side, before the BMS**, so it can never be disconnected ([SAFETY.md](SAFETY.md)). |
| 10 | **LiFePO4 won't charge below 0 °C** — silent winter failure. | **DOCUMENTED** — BOM requires a BMS **with low-temp charge cutoff**; winter pull-out already in SAFETY. |

## 🟡 Moderate — cost, wear, and honesty items

| # | Finding | Resolution |
|---|---|---|
| 11 | Bulkhead spec said "print in polycarbonate" — hobby PC printing is impractical, and the part is just a flat disc. | **DOCUMENTED** — **cut it from 3 mm PC/acrylic/FR4 sheet**; the STEP file is the drill/routing template. |
| 12 | End plate Ø370 mm also exceeds print beds. | **DOCUMENTED** — cut from HDPE sheet / plywood for large rotors using the STEP as template; printing is for small rotors. |
| 13 | Wet coupling-disc magnets "epoxied in" is not marine sealing — NdFeB rusts through pinholes. | **DOCUMENTED** — pot pockets full, then a **thin epoxy/glass cover coat over the whole magnet face**; inspect seasonally. |
| 14 | "Charge a laptop" needs actual hardware, not just Wh. | **DOCUMENTED** — BOM adds a **12 V → USB-C PD (45–65 W) buck module**; battery must sustain ~5 A bursts. |
| 15 | Sediment deposition behind the funnel throat buries the bottom bearing. | **DOCUMENTED** — keep the lower bearing ≥ skid height off the bed; seasonal check. Sediment is also why the base uses a skid, not feet. |
| 16 | Lab/CFD Cp values (0.19/0.24 profiles) will run 20–30 % lower in a real build. | **ACCEPTED** — defaults stay conservative (`custom` 0.18); profile presets note CFD optimism ([RESEARCH_ROTORS.md](RESEARCH_ROTORS.md) caveats). |
| 17 | Trash rack orientation/limits under-specified — a clogged rack *is* the blockage. | **DOCUMENTED** — mount angled, bars aligned with flow, sized via `siting.screen_*`; clean-by-design expectations in [FUNNEL.md](FUNNEL.md). |
| 18 | Funnel throat concentrates debris — clog rate scales with the speed-up. | **ACCEPTED + DOCUMENTED** — the trash rack is **mandatory** with a funnel; maintenance interval is site-dependent (OPEN: measure it). |

| 19 | **Bulkhead O-ring groove collided with its bolt holes** (groove Ø153.5–156.5 vs bolt holes spanning Ø150.25–155.75) — found while detailing the full-unit CAD; the part would not have sealed. | **FIXED-IN-CODE** — flange widened +8 mm, groove moved 8 mm inboard of the bolt circle; part re-exported. A good example of why the hyper-detail pass exists. |

## What deliberately remains open (needs a wet prototype, not more modeling)

Each open item now has a concrete procedure with pass/fail gates and a
feed-back-into-config step in **[TEST_PROTOCOL.md](TEST_PROTOCOL.md)**:

1. Field-calibrated funnel `confinement` → protocol **F2**.
2. Measured rotor Cp vs. the profile presets → protocol **F3**.
3. Real fouling/sediment maintenance interval → protocol **F4**.
4. Coupling slip torque verified on the bench → protocol **B2**
   (plus generator cut-in **B1**, drivetrain drag **B3**, watertightness **B4**,
   controller idle **B5**).

*Everything in the tables is implemented in the same commit series that added this
file; `python -m pytest` (115 checks) and `python -m cad.export_all` (7 parts)
verify the claims that are verifiable in software.*

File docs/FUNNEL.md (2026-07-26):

# The funnel — making a mellow, shallow creek charge a laptop

> "Couldn't a funnel let 6 inches do the trick, because it's almost funneled into
> more?"

**Yes — and this is the single best move for a mellow, shallow creek.** Wall the
creek into a **converging chute** so the flow squeezes through a narrow throat at
the rotor. It speeds up, and because power ∝ v³ the payoff is huge. Model it:

```bash
python -m scripts.funnel --up-vel 0.4 --up-width 1.5 --up-depth 0.3 \
                         --throat-width 0.4 --throat-depth 0.15
```

## Why it works — you tap the creek's *flow*, not just its speed

Continuity: `A₁·v₁ = A₂·v₂`. Squeeze the same water through a smaller opening and
it accelerates. The deeper insight is what you're actually harvesting:

> **P_available = ½·ρ·A_throat·v_throat³ = ½·ρ·Q·v_throat²**

Because `A·v = Q` (the creek's flow rate), the funnel routes the **whole creek's
discharge Q** through the rotor at an elevated speed. A lazy creek that's useless
to a small bare rotor still carries a lot of *water per second*; the funnel turns
that flow into power. A bare rotor sips; a funnel drinks.

## The honest ceiling: critical velocity

An **open-channel** constriction can't accelerate flow past the **critical
velocity** at the throat depth:

> **v_critical = √(g · y)**

Narrow it further and the flow **chokes** — it just ponds up upstream instead of
going faster. The happy accident: at **6 inches (0.15 m)** that ceiling is
**√(9.81 × 0.15) ≈ 1.2 m/s**, which is right where a 6-inch rotor starts charging
a laptop. So the funnel's natural cap in shallow water lands exactly where you need
it.

## Your numbers (a mellow creek, funneled into 6 inches)

A **0.40 m/s** creek, **1.5 m wide × 0.30 m deep** (Q ≈ 180 L/s), funneled to a
**0.40 × 0.15 m** throat:

| | Bare rotor | **Funnelled rotor** |
|---|---|---|
| Velocity at rotor | 0.40 m/s | **1.21 m/s** (choked at critical, 3.0×) |
| Power | 0.2 W | **5.6 W** (~28× — the v³ law) |
| Per day | ~4 Wh | **~101 Wh/day → ~1.4 laptop charges** |

So a funnel turns a mellow, 6-inch creek from "charges nothing" into "tops up a
laptop and your phones every day." That is the whole game.

## Two ways to funnel — and the honest cost of "works in any creek"

There's a real fork here:

- **Bank-to-bank weir (site-specific):** walls reach both banks, so *all* the flow
  must go through the throat. It ponds up and reaches the full choke-to-critical
  speed-up — the big numbers above. But it's a fixed structure built for one spot.
- **Free-standing universal unit (portable):** a self-contained funnel with a
  **fixed intake width** (angled wing-walls that gather a set swath) that you drop
  into *any* creek wider than its mouth. Water outside the mouth simply flows
  around — which is also why it realizes **less** than the ideal speed-up: with an
  open bypass beside it, some gathered flow spills back out instead of forcing
  through. The model captures this with a **`confinement`** factor (~0.82 for a
  free-standing unit; 1.0 for a walled weir).

  > ⚠ **`confinement` is an engineering assumption, not a measured value.** The
  > literature has no clean number for a free-standing intake in an open creek,
  > and the real figure could plausibly be 0.6–0.9 depending on wing-wall length
  > and bed sealing. **Field-calibrate it**: float a stick through the throat,
  > time it, and set `confinement` so the model matches — *then* trust the watts.
  > The unit also can't gather deeper than its own mouth (`intake_height`), which
  > the model now caps.

### A universal unit for any creek ≥ 4 ft wide

Give it a **0.9 m (3 ft) gather mouth** and it fits any creek wider than ~4 ft
(3 ft mouth + margin), using only part of a wider creek's width — exactly what you
want. Its power then depends on **depth**, because it funnels the *full* approach
depth down into the short (6-inch) rotor throat:

```bash
python -m scripts.funnel --universal --up-vel 0.4 --gather-width 0.9
```

A **mellow 0.4 m/s** creek, free-standing unit (0.82 confinement):

| Water depth | Throat speed | Power | Per day | Laptop charges/day |
|---|---|---|---|---|
| 6 in (0.5 ft) | 0.81 m/s | 1.7 W | 30 Wh | 0.4 (continuity) |
| 1 ft | 1.07 m/s | 3.8 W | 69 Wh | **1.0** (choked) |
| 1.5–3 ft | 1.07 m/s | 3.8 W | 69 Wh | **1.0** (choked) |

So the universal unit **charges a laptop daily in ≥ ~1 ft of water** and derates
gracefully to ~0.4/day at the 6-inch extreme. Once it chokes (~1 ft+), deeper water
doesn't add more — the throat is capped at critical × confinement — so the ceiling
for the free-standing form is ~4 W here. To push past it at a chosen site, add
**temporary bank wing-walls** (confinement → 1.0 gives ~5.6 W) or a bigger throat.

## The catches (be honest before you dig)

- **It's a small weir, not a drop-in.** To stop water bypassing, the funnel walls
  must reach **both banks** — you're building a low wing-wall structure spanning
  the creek, not dropping in a box.
- **It ponds the upstream level.** The choked flow backs water up (that's where the
  speed-up energy comes from). Fine on a steep reach with room; a problem if it
  floods something upstream.
- **Bigger permit / fish-passage footprint.** Walling and ponding a creek edges
  toward "diverting" it — check water rights and fish rules first
  ([SITING.md](SITING.md#4-permits--neighbors-do-this-before-you-build)). Leave a
  fish/overflow bypass.
- **Debris clogs a throat faster** — an upstream **trash rack** is mandatory
  ([the `trash_rack` part](../cad/README.md)).
- **To go faster than critical**, you need a **closed, pressurized duct with real
  head** (a pipe from an upstream pool) — the [box-with-head design](BOX_AND_DUCT.md),
  not an open funnel.

## Design tips

- Make the throat roughly the **rotor size** so the rotor intercepts the sped-up
  flow instead of letting it bypass.
- A **gentle contraction** (long, smooth wing walls, ~a 3:1 length:offset taper)
  loses less energy than an abrupt one.
- **Deepen the throat if you can** — critical velocity rises with √(depth), so
  ponding to a slightly deeper throat raises the ceiling and the power.
- Feed the resulting multiplier back into the sizing: set
  `VELOCITY_AUGMENTATION = throat_velocity / creek_velocity` in `config.py` and
  re-run `size_turbine`.

## What's modeled

`creekturbine/funnel.py` (tested in `tests/test_funnel.py`):

- `critical_velocity` / `froude_number` — the open-channel ceiling
- `FunnelIntake` — approach + throat → throat velocity (with choke), power, and the
  gain vs a bare rotor
- `throat_width_for_velocity` — size the throat for a target speed (capped at critical)

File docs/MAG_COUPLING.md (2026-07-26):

# Magnetic coupling — sealing the wet→dry shaft crossing

The turbine is wet; the generator and electronics are dry. Something has to carry
torque across that boundary. A shaft seal (lip/mechanical) is the classic answer —
and the classic **#1 leak point** on any submerged machine. A **magnetic coupling**
removes the problem entirely: it transmits torque **through a solid, unbroken
wall** with nothing penetrating it.

```
   generator shaft ──┬── [ dry magnet disc ]        DRY
                     │        ↕ magnets            (sealed housing)
   ══════════════════╪══════════════════════  sealed non-magnetic bulkhead
                     │        ↕ magnets            WET
   rotor shaft ──────┴── [ wet magnet disc ]      (in the water)
```

Two coaxial discs each carry a ring of magnets in **alternating polarity**. Turn
the wet disc and the dry disc follows in lock-step. **Bonus safety feature:** if
you overload it (a jam, a flood), the magnets simply **slip** past each other
instead of breaking anything — a built-in torque limiter.

Size it for your rotor with:

```bash
python -m scripts.mag_coupling            # sizes to the rotor torque from config.py
python -m scripts.mag_coupling --gap 2 --magnet-dia 20 --grade N52
```

## How much coupling you need

The torque a magnetic coupling transmits is, to first order:

> **T_max ≈ τ · A_active · R_mean**

— magnetic shear stress τ, total magnet face area A_active, and mean radius R_mean.
For NdFeB at a small gap, τ lands around **10–40 kPa**. For our default rotor
(~2 N·m at 40 rpm), a coupling of **12 × Ø15×6 mm N42 magnets per disc on a 110 mm
ring at a 3 mm gap** gives ~**4.2 N·m** — holding the rotor torque with a 2× margin
(τ ≈ 36 kPa, effective field 0.87 T). The model is in `creekturbine/magnetics.py`.

⚠️ **Treat the number as a sizing estimate to bench-test, not a guarantee.**
Magnetics is gap-sensitive and the shear coefficient is approximate; build it and
confirm the slip torque before you rely on it.

## ⚠ The axial pull nobody warns you about

The same magnets that make torque **attract the two discs toward each other with
a constant ~350–400 N (~35–40 kg)** for the default coupling
(`AxialMagCoupling.axial_force_n()`, printed by `scripts.mag_coupling`). This
force rides on the **shaft bearings of both discs** — the non-magnetic bulkhead
between them feels none of it — and it will grind plain radial bearings flat in
weeks. **Fit thrust bearings (or angular-contact bearings) on both shafts**,
rated ≥1.5× the printed pull, and make sure the shaft retention (circlips/collars)
carries the load without letting a disc creep into the bulkhead.

## Design levers (in order of impact)

1. **Keep the GAP small.** Field falls off as ~`t/(t+gap)`, so a thick bulkhead
   quietly kills the coupling. Use a **thin, strong, non-magnetic** bulkhead
   (2–3 mm polycarbonate, fiberglass, or aluminium/316 stainless — *not* ordinary
   steel, which shorts the flux). Practical tip: **don't print the bulkhead** —
   it's a flat disc, so **cut it from 3 mm PC/acrylic/FR4 sheet** and use the
   STEP file as the drill template.
2. **Bigger mean radius** — torque scales linearly with R, so spread the magnets
   out on a larger ring.
3. **More / bigger magnets** — active area scales the torque directly.
4. **Stronger grade** — N52 > N42 > N35; ferrite works but needs many more.

## Building it

- Print **two** `mag_coupling_disc` parts (`cad/`). One goes on the wet rotor
  shaft (magnets facing **up** to the bulkhead), one on the dry generator shaft
  (magnets facing **down**).
- Press cylindrical magnets into the pockets in **alternating polarity**
  (N, S, N, S …) — the two discs' rings must mirror each other so N faces S.
  A dab of epoxy keeps them seated; **mind your fingers**, these snap together hard.
- Set the running gap with the bulkhead thickness + a small clearance each side.
- Corrosion: the **wet** disc's magnets must be properly potted — fill the
  pockets with epoxy **and lay a thin continuous epoxy/glass cover coat over the
  whole magnet face**. A dab of glue is not marine sealing; NdFeB rusts through
  pinholes. Inspect seasonally.

See the bulkhead and dry-stack layout in [SELF_CONTAINED.md](SELF_CONTAINED.md) and
[BOX_AND_DUCT.md](BOX_AND_DUCT.md).

## What's modeled

`creekturbine/magnetics.py` (tested in `tests/test_magnetics.py`):

- `magnetic_pressure` / `gap_field` / `shear_stress` — the underlying magnetics
- `AxialMagCoupling` — a two-disc coupling → `max_torque()` and `holds(torque)`
- `magnets_needed(...)` — the magnet count to carry a torque with a safety margin

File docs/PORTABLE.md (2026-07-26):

# Portable creek power station — power anywhere there's moving water

> "Could this be portable (maybe slightly heavy) to use near any creek — backyard
> or camping — with a waterproof cable to shore, a battery, and a way to switch
> sources?"

**Yes, and it's a genuinely good product concept.** You've described a portable,
battery-buffered hydro generator — like a solar power station, but it works
**24/7: at night, in rain, in shade.** That continuous, weather-proof output is
the whole reason to carry one. Model it for your creek and kit with:

```bash
python -m scripts.portable --rotor-area 0.15 --battery-wh 500 --bus 48 \
                           --cable-length 25 --cable-area 4 --burst-load 60
```

## Architecture (this is the important part)

```
  IN THE WATER                 CABLE (low-voltage DC!)      ON DRY LAND
 ┌──────────────────┐                                    ┌───────────────────────┐
 │ rotor → sealed   │   ═══ marine cable, IP68 potted ══ │ charge controller     │
 │ generator (PMA)  │   ═══ connectors, 12–48 V DC   ═══ │  (MPPT, multi-input)  │
 │ +3-phase rectifier│                                   │        │              │
 └──────────────────┘                                    │   LiFePO4 battery     │
   Savonius = drop-in-any-creek                           │        │              │
   (self-starts, ignores flow direction)                 │  USB / USB-C / 12 V   │
                                                          │  (+ inverter → 120 V) │
                                                          └───────────────────────┘
```

**Three rules that shape everything:**

1. **The in-water cable is LOW-VOLTAGE DC (12–48 V), never mains AC.** The
   generator rectifies to DC right at the unit; only safe low-voltage DC travels
   the "extension cord." Any 120/230 V AC inverter lives **on dry land, after the
   battery** — never in or near the water. This is a safety hard rule.
2. **Loads run off the battery; the turbine tops it up.** That's what makes the
   output *sustained and smooth*: full power the instant you arrive (pre-charged),
   steady even when the creek is weak or gusty, and the ability to briefly **burst**
   a load bigger than the turbine makes.
3. **Keep the battery + electronics on shore.** Only the sealed generator and the
   cable get wet — the safest, most serviceable split.

## Your "switch between sources," done right

Rather than a manual A/B switch, use a **multi-input charge controller**: the same
battery accepts the **turbine**, and optionally **solar** and a **wall/USB-C**
charger. Loads always draw from the battery, so you never notice the handoff —
the creek charges it by day and night, solar helps when sunny, and a wall outlet
tops it off before you leave home. (If you specifically want to run a device
*directly* off the turbine and bypass the battery when flow is strong, a simple
DPDT source selector can do that — but the battery-buffered path is smoother and
protects the electronics.)

## Honest power expectations (from the model)

A compact portable rotor (~0.1–0.2 m²) is small on purpose. Realistic output:

| Creek speed | ~Continuous harvest (0.15 m² Savonius) | Feels like |
|---|---|---|
| 0.4 m/s (lazy) | ~0.5 W | slow phone top-ups |
| 0.8 m/s (healthy) | ~4 W (~95 Wh/day) | phones + lights + sensors, 24/7 |
| 1.2 m/s (brisk) | ~14 W (~330 Wh/day) | + a power bank, camp fridge trickle |

The battery lets you **burst** bigger loads (e.g., a 60 W device off a 500 Wh
pack for ~8 h) — but on a weak creek the turbine may take **days** to refill that,
so treat bursts as occasional. The bread-and-butter is the *sustained* few watts
that never stop. Want real power (tens–hundreds of watts)? Combine this with the
**built-in-head "box" design** in [BOX_AND_DUCT.md](BOX_AND_DUCT.md).

## The cable — the sneaky-hard part

Volt-drop over a long low-voltage run is brutal (`loss = I²R`). The model sizes
it, and the takeaway is: **for a long run to shore, use a higher bus voltage.**
Because current scales as 1/voltage for the same power, going 12 V → 48 V cuts the
required copper by ~16× (or the loss at the same gauge). So a 48 V generator with
a step-down on land beats a 12 V one for anything beyond a few meters — the cable
matters most once you're harvesting tens of watts (a brisk creek or the head-box
design). Use **marine tinned cable** and **IP68 potted/gel connectors**; seal
every junction as if it'll be underwater, because it will be.

## Deploy-anywhere checklist

- [ ] **Sealed generator** (potted PMA) or a **magnetic coupling** so nothing can
      leak — see [BOX_AND_DUCT.md](BOX_AND_DUCT.md#crossing-the-wetdry-wall--use-a-magnetic-coupling)
- [ ] **Savonius rotor** sized to submerge in your shallowest expected creek
      (drop-in, direction-agnostic, self-starting — ideal for "any creek")
- [ ] **Fast anchor**: stake + guy line, sandbags, or wedge between rocks; a
      trash screen upstream
- [ ] **Low-voltage DC** cable, marine-grade, IP68 connectors; inverter on land only
- [ ] **Battery + multi-input controller** on shore, **fused** at the battery
- [ ] Leave home with the pack **pre-charged** (wall/solar) so you have power on arrival
- [ ] Check local rules before deploying on water that isn't yours
      ([SITING.md](SITING.md#4-permits--neighbors-do-this-before-you-build)) and
      read [SAFETY.md](SAFETY.md)

## What's modeled

`creekturbine/portable.py` (tested in `tests/test_portable.py`):

- `runtime_hours` / `sustained_load_w` / `burst_runtime_hours` / `recharge_hours`
  — the battery-buffer math (sustained vs. burst vs. refill)
- `cable_voltage_drop` / `min_cable_area_mm2` — size the "waterproof extension
  cord" and see why higher voltage wins on a long run
- `battery_mass_kg` / `pack_weight_kg` — the carry-weight budget
- `PortableUnit` — ties creek speed + rotor + battery + cable into one report

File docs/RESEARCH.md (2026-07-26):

# Research — the physics behind the numbers

The toolkit is deliberately built on textbook fluid mechanics, not vendor claims.
This page records *why* the equations and default coefficients are what they are,
so you can push back on them for your own site.

## Core equations

- **Kinetic power flux.** A stream of density ρ moving at speed v carries kinetic
  energy ½mv²; the mass flow through area A is ρAv, so the power is
  **P = ½·ρ·A·v³**. This is the same equation used for wind, with water's density
  (~1000 kg/m³) instead of air's (~1.2). Water is ~800× denser than air, which is
  why a slow, small water rotor rivals a big wind turbine — but the **v³** term
  means slow water is still stingy.
- **Betz limit.** An open (unshrouded) rotor cannot extract more than
  **16/27 ≈ 59.3%** of that kinetic power, because the water it slows must still
  move on to make room for the water behind it. Derived by Betz (1919) for a
  actuator-disc in an unbounded flow. It is a hard ceiling on Cp; every real
  number in this repo sits well below it. (A *shroud/diffuser* can beat the bare-
  rotor Betz value for a given swept area by drawing in extra flow — that's why
  augmentation is modeled separately.)
- **Power coefficient Cp.** The captured fraction, `P_rotor = Cp · P_available`.
- **Tip-speed ratio TSR = ωR/v.** Cp peaks at a rotor-specific TSR.

## Default coefficients (conservative on purpose)

| Quantity | Default | Why |
|---|---|-----|
| Cp, Savonius | 0.18 | Drag-type VAWTs typically test at Cp ≈ 0.15–0.25; lab-optimized profiles reach ~0.25–0.30. A DIY cut-pipe rotor lives at the low end — 0.18 is honest, not rosy. |
| Optimal TSR, Savonius | ~0.9 | Drag rotors peak just below TSR = 1 (the scoops can't outrun the water). |
| Cp, axial | 0.35 | Small hydrokinetic propellers report Cp ≈ 0.35–0.45; good tidal rotors approach the mid-0.4s. 0.35 is a safe DIY assumption. |
| Optimal TSR, axial | ~5 | Lift-type rotors run fast (TSR 4–7). |
| Generator efficiency | 0.65 | A small PMA at low rpm plus a diode rectifier: 60–75% is realistic; big claims are for the rated point, not creek rpm. |
| Drivetrain efficiency | 0.90 | Bearings, seal drag, coupling/belt. |
| Surface→mean velocity | 0.85 | Standard correction: a surface float reads faster than the depth-averaged mean in a small natural channel. |

The result — an end-to-end "water→battery" efficiency around **10–11%** for a
Savonius, **~20%** for an axial — is deliberately on the pessimistic side so real
builds *beat* the estimate rather than disappoint. Tune the values in
`config.py` if you have measured data for your own parts.

> **Rotor geometry deep-dive:** for a cited, adversarially-verified survey of
> which rotor shapes maximize Cp *and* survive an unattended creek — optimized
> and hydrofoil Savonius blades, helical twist, hybrid Savonius–Darrieus,
> shrouds, and frontier VIV/flapping-foil harvesters — see
> **[RESEARCH_ROTORS.md](RESEARCH_ROTORS.md)**. Its findings back the selectable
> `SAVONIUS_PROFILE` presets and the printable helical blade in `cad/`.

## Why hydrokinetic (no dam)

Conventional micro-hydro multiplies **head × flow** and wants a vertical drop
(a pipe/penstock from higher ground). A flat creek has almost no head, so the
kinetic route — an "underwater wind turbine" — is the honest match. It's also the
low-impact, usually-more-legal choice: no dam, no diversion, removable.

## Good places to read further

- Betz's law and actuator-disc theory (any wind-energy textbook; the derivation
  is identical for water).
- Savonius rotor performance studies (aspect ratio, overlap ratio, end plates,
  2- vs 3-bucket) — these set the geometry defaults in `cad/params.py`.
- Hydrokinetic / micro-hydro guides from small-turbine communities for the
  generator-matching, rectifier, and dump-load practice.
- Your local water authority and fish & wildlife office for the rules that
  actually apply to your creek.

*(This file intentionally cites principles rather than specific pages/prices,
which drift. The equations are stable; verify coefficients against your own
bench measurements in Phase 2.)*

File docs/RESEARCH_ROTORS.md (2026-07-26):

# Rotor geometry research — maximizing Cp *and* surviving the creek

A multi-source, **adversarially-verified** literature pass on experimental and
optimized hydrokinetic rotor geometries, scoped to our goal: high power
coefficient (Cp) at **low creek speeds (~0.4–1.2 m/s)** in a **small,
self-contained, vertical-shaft unit** that must run **months unattended in
debris-laden water**.

**Method / confidence:** 5 search angles → 23 sources → 75 extracted claims → the
top 25 verified by 3 independent skeptics each (a claim needs 2/3 to survive).
Result: **22 confirmed ✅, 3 refuted ❌, 0 unverified.** Confidence is noted per
claim. Several headline Cp figures are **CFD/numerical only** — flagged, and to be
discounted for simulation optimism (real built rotors land lower).

## Bottom line

For an unattended low-speed creek unit, the peer-reviewed evidence points to an
**optimized drag-type Savonius** (optionally helical, with end plates) as the best
balance of Cp and robustness. The high-Cp lift geometries win on paper and lose on
self-start and durability — exactly the wrong trade for water you can't babysit.

## The core tension (✅ high confidence)

✅ **Savonius Cp ≈ 0.12–0.25 at TSR ≈ 0.35–1.0 and self-starts; Darrieus Cp ≈
0.29–0.40 but only at TSR ≈ 1.5–3.5 and struggles to self-start at low speed.
Self-start improves with solidity; torque ripple falls as blade count rises.** [1]
For water you can't restart by hand, the higher-solidity Savonius end is the safe
choice. (A broad "Gorlov helical reaches Cp ~0.45" claim from the same review was
**❌ refuted** — do not rely on it.)

## (1) Making a Savonius much better without losing its toughness

✅ **Blade-shape optimization is the biggest low-cost lever.** An ANN/CFD-optimized
semicircular rotor — **arc angle ≈ 166°, aspect ratio 1.4–2.0, overlap 0.15–0.2,
end plates** — reaches **Cp 0.194 at TSR 0.8** (experimentally validated to ~1.6%).
[5] Among novel cross-sections, a **V-shaped** blade gave the best Cp 0.184 (U
0.172, conventional 0.166, **W 0.160 — worse than stock**), all at TSR 0.78. [2]
Profile choice can help *or* hurt.

✅ **A cambered-hydrofoil Savonius blade nearly DOUBLES Cp at very low flow:
Cp 0.21 at 105° camber → 0.26 at 140°, vs 0.13 conventional, at 0.4 m/s and
overlap 0.15.** [3] ⚠️ **Caveat:** 3D RANS **CFD only**, and the 0.13 baseline is
low — expect real numbers below 0.26. This is the strongest low-speed Cp lever
found, but an accurate cambered section is harder to fabricate than a plain bucket.

✅ **Helical/twisted blades** don't reliably raise peak Cp (that's why we set
`helical` as a self-start/robustness feature, not a Cp bump), but they remove the
Savonius's angular dead-spots, **smooth torque ripple, and shed debris** — all
gold for an unattended creek unit.

✅ **Hybrid Savonius–Darrieus:** in one experiment-validated CFD study, **~9.9%
higher Cp and ~15.9% higher torque than a lone Darrieus, with less ripple**, and
the Savonius stage shrinks the Darrieus negative-torque "dead band" from three
azimuth ranges to one (big self-start win). [4] ⚠️ **Caveat:** that Cp *gain* is
configuration-specific — much of the hybrid literature finds an added Savonius
stage *reduces* peak Cp (you buy self-start at the cost of efficiency). Trust the
self-start/ripple benefit more than the +10% Cp.

## (2) Flow augmentation (shrouds/diffusers) — real but conditional

✅ A cascade-designed **diffuser-augmented rotor reached ducted Cp ≈ 0.415**
(normalized to the diffuser's outer area, CFD), [6] and ✅ the brimmed "wind-lens"
mechanism **transfers to water — a water-lens turbine shows ~2.5× power** vs a bare
rotor. [7][8] **But:** ❌ the generic **"2–5× for any bare rotor" claim was
refuted**, and the blockage-correction literature warns diffuser gains are
"significantly overestimated in a confined [test-tank] domain" — an open,
low-blockage creek sees **less**. And a shroud is a **debris-clog and biofouling
liability**. Net: a real lever (folds into our [BOX_AND_DUCT.md](BOX_AND_DUCT.md)
head design), not a free win. Axial propellers reach the highest bare-rotor Cp
(~0.35–0.45) but need fast flow to start and have erosion-prone blades.

## (3) Frontier / experimental — real low-speed promise, "watch, don't build"

Now **verified but heavily caveated** — genuinely interesting, not yet buildable:

✅ **VIV harvesters (VIVACE):** ~**98 W/m³ at 1.03 m/s** (including dead space
between cylinders), with experiments across **0.4–1.1 m/s** — squarely our window.
[9] ✅ Among flow-induced-vibration types, **galloping gives higher power, VIV
higher efficiency, and a wake-induced-vibration** circular oscillator is the
balanced optimum. [10] ✅ Low spring stiffness + passive turbulence control push
power **onset down to 0.2 m/s**. [11] ✅ **Tandem flapping hydrofoils** are
optimized for ~1 m/s currents at ~**66.8% CFD efficiency**. [12]

⚠️ **Why these stay on the watch list:** (a) power ∝ v³, so *net* harvest at
0.2–0.4 m/s is tiny; (b) the 66.8% is swept-area-defined and **exceeds the Betz
limit** — it is not comparable to rotor Cp and not a field number; (c) all are
lab/CFD-stage with moving linkages and no long-term field record. (One FIV ranking
sub-claim — "a fluttering foil ranks third" — was ❌ **refuted 0-3**.)

## (4) Durability — and why it *reinforces* the Savonius choice

✅ **The dominant blade-degradation mechanisms are suspended-sediment abrasion,
debris impact, fatigue, and biofouling; leading-edge erosion is the most
performance-critical location — on LIFT-based blades**, because it disrupts the
flow separation/stall that lift depends on. [13]

⚠️ **Crucial scope caveat (from verification):** that source is a *tidal* study at
**2–4 m/s**. At creek speeds (0.4–1.2 m/s), **cavitation is negligible**, and a
**drag-based Savonius has no lift-critical leading edge** to erode — its torque
comes from the concave/convex drag difference of a thick, blunt scoop. So the
scary failure modes hit exactly the high-Cp lift rotors, **not** the Savonius. For
our unit the real risks are **bearing/seal wear, sediment abrasion, biofouling,
debris strikes, and fatigue** — addressed by a blunt self-shedding rotor, an
upstream trash rack ([SITING.md](SITING.md)), and robust materials.

## Ranked recommendation for a buildable self-contained creek unit

1. **Optimized Savonius — the pick.** Helical/twisted blades, **end plates**,
   **aspect ratio 1.4–2.0, overlap 0.15–0.2, arc ~166°** (or a cambered profile if
   you can build it). Self-starts, debris-tolerant, easiest to build; Cp ~0.19–0.25.
2. **Hybrid Savonius–Darrieus** — more Cp/torque with retained self-start, more
   parts. Good if your flow is brisker and cleaner.
3. **Cambered-hydrofoil / V-profile Savonius** — highest low-speed Cp (CFD to 0.26)
   *if* you can fabricate the section accurately.
4. **Watch, don't build:** VIV/VIVACE/galloping and flapping-foil harvesters —
   real low-speed promise, but lab/CFD, tiny net power, moving parts.
5. **Avoid for unattended low speed:** bare Darrieus/H-rotor (poor self-start) and
   tight shrouds (debris/fouling liability; tank-inflated numbers).

**What we did in the code:** `rotor.py` carries these as selectable
`SAVONIUS_PROFILES` (conventional 0.16 / optimized 0.19 / hydrofoil 0.24 — the
hydrofoil value deliberately sits *below* the CFD 0.26 peak), `from_profile()`
tags a `helical` flag, and `cad/` ships a printable **helical Savonius blade**.
Defaults stay conservative; opt into a profile for the researched gain.

## Comparison table (from the verified synthesis)

| Geometry | Typical Cp | Optimal TSR | Self-start | Durability (creek) | DIY-buildable |
|---|---|---|---|---|---|
| Conventional Savonius | 0.12–0.19 | 0.7–1.0 | Excellent | High (blunt, drag) | Easy |
| **Optimized Savonius** (arc/AR/overlap, end plates) | **0.19–0.25** | ~0.8 | Excellent | High | Easy–Moderate |
| **Helical/twisted Savonius** | ~0.18–0.25 | ~0.8 | Excellent (no dead angle) | High + self-shedding | Moderate |
| Cambered-hydrofoil / V-profile Savonius | 0.18–0.26 (CFD) | 0.78–0.8 | Good–Excellent | High | Moderate–Hard |
| Hybrid Savonius–Darrieus | ~0.25–0.35 | ~1–2 | Good (dead band shrunk) | Moderate–High | Moderate |
| Darrieus / H-rotor | 0.29–0.40 | 1.5–3.5 | Poor at low speed | Moderate (thin-LE erosion) | Moderate |
| Diffuser/shroud (DAWT) | up to ~0.42 ducted (~2.5×, blockage-inflated) | rotor-dependent | inherits rotor | **Low** (debris clog/foul) | Hard |
| Axial propeller | 0.35–0.45 | 4–7 | Poor at low speed | Moderate (LE erosion) | Hard |
| FIV/VIV/VIVACE, flapping foil | n/a (lab/CFD) | n/a | onset ~0.2 m/s, tiny net power | Unproven | Not yet |

## Caveats worth remembering

- **CFD optimism:** the 0.26 hydrofoil Cp, 0.415 ducted Cp, and 66.8% flapping-foil
  efficiency are simulations; real builds land lower. Swept-area efficiencies that
  exceed the Betz limit (0.593) are defined differently and aren't comparable to Cp.
- **Shroud numbers are tank-inflated;** open-creek gain is smaller and comes with a
  debris/fouling maintenance burden.
- **Hybrid's +9.9% Cp is one config;** the reliable benefit is self-start + ripple.
- **The durability study is tidal (2–4 m/s);** its cavitation/leading-edge emphasis
  does **not** transfer to a low-speed drag Savonius.
- **Almost no source reports true months-long unattended field endurance** for a
  small DIY rotor — durability conclusions are extrapolated from larger tidal work
  and erosion physics, not directly comparable creek trials.

## Open questions (good next experiments)

1. Measured (not CFD) Cp and multi-month endurance of an optimized helical or
   cambered Savonius at 0.4–1.2 m/s in a real debris-laden creek, including
   bearing/seal wear and fouling-driven Cp decay.
2. True open-channel (blockage-corrected) shroud multiplier — does the net gain
   survive the added clogging/fouling maintenance?
3. Trash-rack / blockage-ratio / blade-edge geometry that minimizes jamming while
   preserving self-start torque — and how much Cp that costs.
4. Low-cost DIY materials/coatings (HDPE/UHMW, epoxy-glass, antifouling) that best
   resist sediment abrasion, biofouling, and fatigue at this scale.

## Sources

1. Vertical-axis hydrokinetic turbines review — sciencedirect.com/science/article/pii/S235248472500695X ✅
2. Savonius blade-profile CFD (U/V/W) — sciencedirect.com/science/article/abs/pii/S0029801821009926 ✅
3. Cambered-hydrofoil Savonius (Ocean Eng. 292, 2024) — sciencedirect.com/science/article/abs/pii/S0029801823029451 ✅
4. Hybrid Savonius–Darrieus — sciencedirect.com/science/article/pii/S235248471930962X ✅
5. Optimized semicircular Savonius (Renewable Energy 200, 2022) — sciencedirect.com/science/article/abs/pii/S0960148122015142 ✅
6. Cascade diffuser-augmented rotor (Cp 0.415) — sciencedirect.com/science/article/abs/pii/S0960148123005219 ✅
7. Flanged diffuser (wind-lens flange effect) — sciencedirect.com/science/article/abs/pii/S0960148118302441 ✅
8. Wind-lens / water-lens (~2.5×) — researchgate.net/publication/312564963 ✅ (generic 2–5× ❌ refuted)
9. VIVACE (vortex-induced vibration) — asmedigitalcollection.asme.org/.../471896 ✅
10. Flow-induced-vibration harvester comparison — sciencedirect.com/science/article/abs/pii/S0960148121018565 ✅ (one sub-claim ❌ refuted)
11. Flow-induced oscillation at 0.2 m/s — sciencedirect.com/science/article/abs/pii/S0960148123007437 ✅
12. Tandem flapping-hydrofoil optimization — sciencedirect.com/science/article/abs/pii/S0029801824020110 ✅
13. Tidal-blade erosion mechanisms (Eng. Failure Analysis, 2025) — sciencedirect.com/science/article/pii/S1350630725007861 ✅
14. Field-testing of model helical-bladed hydrokinetic turbines — sciencedirect.com/science/article/abs/pii/S0960148118304609

**Refuted (do not cite as fact):** Gorlov helical Cp ~0.45 [1]; generic wind-lens
2–5× multiplier [8]; "fluttering foil ranks third among FIV harvesters" [10].

*Full run: 25 claims verified (3 votes each) → 22 confirmed, 3 refuted, 0 unverified.*

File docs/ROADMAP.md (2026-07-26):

# Roadmap — de-risk in software, then build

The philosophy: prove the numbers work for *your* creek (free) before spending on
parts, and tackle the genuinely hard bits (the generator, waterproofing, floods)
deliberately rather than by surprise.

| Phase | What | Cost |
|---|---|---|
| **0** ✅ | Physics & sizing engine, all subsystem models, simulator, 115 tests | Free (software) |
| **0.5** ✅ | Research (verified), red-team audit (19 findings closed), **Mk1 design freeze** ([SPEC.md](SPEC.md)) + **complete CAD** (14 parts + positioned assembly) | Free (software) |
| **1** | Measure your creek in 2+ seasons; print/cut parts; buy the BOM | ~$0 + parts |
| **2** | Bench tests **B1–B5** ([TEST_PROTOCOL.md](TEST_PROTOCOL.md)): cut-in, coupling slip, drag, watertightness, idle draw | 💰 generator + battery |
| **3** | Wet install + field tests **F1–F4**: confinement & Cp calibration, 72 h soak | 💰 full build (~$300–480) |
| **4** | Iterate on calibration data; seasonal hardening (floods, winter) | 💰 iteration |

## What's built today (Phase 0)

- **`hydrokinetics.py`** — `½·ρ·A·v³`, the Betz limit, rotor sizing, rpm/torque,
  and flow-augmentation math, all tested against hand-computed values.
- **`rotor.py`** — Savonius and axial rotor models behind one interface; sizing
  helpers that turn a power target into rotor dimensions.
- **`generator.py`** — PMA cut-in rpm/velocity, charge current/power, and a Ke
  recommender so the generator matches your low-season flow.
- **`energy.py`** — daily/annual energy, battery Ah sizing, and a "what it runs"
  table (phone → fridge).
- **`siting.py`** — the float-method + cross-section measurement math.
- **`ducted.py`** — the enclosed-box / ducted low-head turbine option: throat
  flow, the payoff of adding head, and submerged-box buoyancy/ballast
  ([BOX_AND_DUCT.md](BOX_AND_DUCT.md)).
- **`simulator.py`** + `scripts/` — the sizing report and the figures.
- **`cad/`** — parametric end plates, shaft coupler, generator mount (STEP+STL).

## The genuinely hard parts (called out honestly)

1. **Generator matching** (Phase 2). Low creek rpm vs. a generator's cut-in is
   *the* classic failure. The model makes it visible; the bench test in Phase 2
   is where you prove it with a real part before getting wet.
2. **Keeping the generator dry** (Phase 3). The vertical-axis choice mostly
   solves this — generator on top, only bearings wet — but the shaft, bearings,
   and enclosure sealing still need care.
3. **Surviving the creek** (Phase 3–4). Floods, debris, silt, ice, corrosion.
   Design for removal; over-build the frame and anchors.
4. **Legal & environmental** (Phase 1, ongoing). Water rights and fish passage —
   settle these *before* building. See [SITING.md](SITING.md) and [SAFETY.md](SAFETY.md).

## Ideas for later

- A live logger (ESP32 + INA226 current/voltage sensor) to record real Wh/day
  and validate the model against your creek.
- A 3-scoop Savonius option (smoother torque) and a proper shrouded-rotor model.
- A tuned Cp-vs-TSR curve per rotor instead of a single design-point Cp.

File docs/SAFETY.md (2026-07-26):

# Safety — water + electricity + a spinning machine

This is a device that combines a creek, stored electrical energy, and a rotor
that never wants to stop. Read this before the build, not after.

## Electrical

- **A hydro source runs 24/7 and can't be "switched off" like a panel in the
  dark.** You MUST give the generated power somewhere to go at all times, or the
  turbine free-spins to destruction and the rectifier/voltage spikes.
  → Install a **charge controller with a dump/diversion load** (a resistor bank
  or a heating element) that soaks up power when the battery is full. This is not
  optional on a turbine.
  → **Wire the dump on the GENERATOR side, before the BMS.** The sneaky failure:
  a full or cold battery makes the BMS open its disconnect — and a dump load wired
  behind it vanishes along with the battery, leaving the PMA open-circuit to
  overspeed. The clamp/dump must be somewhere a BMS can never disconnect it.
- **Fuse everything.** A fuse at the battery **+** terminal (sized to the wiring)
  is the single most important safety part in the box. A shorted lead-acid or
  LiFePO4 battery can deliver hundreds of amps and start a fire.
- **Battery chemistry.** LiFePO4 is the safest practical chemistry (no thermal
  runaway like other lithium types) and tolerates cold better than most —
  recommended. Whatever you use, add a **BMS**. Vent lead-acid (hydrogen gas).
- **Ground fault + wet hands.** Even 12 V systems can deliver dangerous currents
  through wet skin, and corrosion is relentless near water. Keep all electronics
  in a **sealed, elevated enclosure**, use marine-grade tinned wire and heat-
  shrink/gel connectors, and add a **GFCI/RCD** on any AC (inverter) output.
- **Never work on the wiring with the rotor free to spin.** Physically **block
  or lift the rotor** (or short the three generator phases together, which brakes
  a PMA) before touching anything.

## Mechanical

- **Overspeed is the enemy.** In a flood the water speeds up and, if the load
  drops out, the rotor can run away. The dump load handles the electrical side;
  also design a **mechanical furling/lift-out** plan and beefy bearings.
- **Pinch & entanglement.** A slow Savonius still has real torque — enough to
  catch fingers, hair, a pet, or a curious kid. Add a **guard/cage**, especially
  if the site is accessible.
- **Anchoring & floods.** Assume the worst storm in your area. Anchor to bed AND
  bank; make the unit removable; never stand downstream of a loaded frame under
  high flow.

## Environmental & legal

- **No dam.** Keep it hydrokinetic and removable. Don't block fish passage.
- **Fluids.** Use food-grade / non-toxic grease on wet bearings; never let oil
  enter the creek.
- **Permits.** See [SITING.md](SITING.md#4-permits--neighbors-do-this-before-you-build) —
  check water rights and environmental rules **before** building.

## A pre-power checklist

- [ ] Battery **fused** at the positive terminal, correct amp rating
- [ ] **Charge controller + dump load** wired and tested (fill the battery and
      confirm the diversion load gets warm)
- [ ] All electronics in a **sealed, elevated** enclosure; marine-grade connectors
- [ ] Rotor **guard** fitted; a way to **brake/lift** the rotor for service
- [ ] Frame anchored to **bed and bank**; **removable** before storms
- [ ] Permits/authority checked; downstream neighbors informed

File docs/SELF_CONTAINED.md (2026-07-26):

# Self-contained all-in-one unit — a box with a handle you set in the creek

> "By portable I just mean the box has a handle on top. I want a fully
> self-contained, almost plug-and-play unit."

That's the cleanest form of the whole project, and the **vertical-axis Savonius is
what makes it possible.** Because the shaft is vertical, the whole machine is a
vertical stack in one housing: rotor at the bottom (wet), everything else stacked
above the waterline (dry). No cable, no separate shore box — carry it, set it in
the stream, and the outlets on top are live.

Self-contained unit

Model it for your creek with:

```bash
python -m scripts.self_contained --box-dia 0.30 --box-height 0.65 --submerged 0.30 --figs
```

## How it's laid out

```
   ┌─ handle ─┐
   │ outlets  │   DRY  — USB / USB-C / 12 V, a little charge display
   │ battery  │  (the "freeboard": the part standing above the water)
   │ generator│   DRY, sealed — magnetically coupled to the rotor below
   ~~~~~~~~~~~~~  waterline
   │  rotor   │   WET — Savonius in the flow (self-starts, any direction)
   └─ base ───┘   weighted / staked so the current can't move it
```

The rotor spins a set of magnets; a matching set on the generator shaft picks that
up **through the sealed bulkhead** (a magnetic coupling — no shaft hole, nothing to
leak). The generator, battery, charge controller, and outlets all live in the dry
upper box.

## Plug-and-play means the electronics manage themselves

- **Self-starting rotor** (Savonius) — no aiming, no manual spin-up, works whatever
  direction the creek runs.
- **Automatic charge controller** — the moment there's flow it charges the internal
  battery; no tuning.
- **Battery always ready** — outlets are live even before the creek does much,
  because you draw from the battery, not the rotor directly.
- **Sealed, protected outputs** — USB/12 V on the dry top, ideally behind a splash
  cover.

Leave home with it charged, set it in the creek, plug in. That's the experience.

## The two things that actually decide if it works

**1. Geometry — does the rotor fit, and does the top stay dry?**
A carriable box is small, so the rotor is small, so the power is small. For a 30 cm
box, ~30 cm deep in a healthy 0.8 m/s creek, the model gives a ~0.065 m² rotor →
**~2 W** (≈45 Wh/day, buffered). The box needs the creek to be at least as deep as
the submerged section, while the top stays above water (the "freeboard") so the
outlets are dry. Want more power? A bigger box, a deeper/faster spot, or the
built-in-head **[box design](BOX_AND_DUCT.md)** — same honest v³ physics.

**2b. The FLOOD case is what actually rips units out.** Drag grows with velocity²,
so a 2.5 m/s storm flow pushes the fully-submerged box with ~**670 N (~10× the
operating load)** — beyond any reasonable ballast. The model prints the flood
drag and required restraint (`flood_drag_n` / `flood_anchor_force_n`); the sane
plan is a **permanent retrieval line to the bank and pulling the unit before
storms**, with the stake/tether as the backstop for the storm you missed.

**2. Stability — will the current push it over or downstream?**
This is the real catch of a free-standing box. The flow exerts a drag force
`½·ρ·Cd·A·v²` on the submerged body — ~32 N for that example, and it grows with v².
A tall box must out-weigh that in both **sliding** (bed friction vs. drag) and
**tipping** (restoring moment vs. overturning moment). The model sizes the base
ballast; for the example it's a modest **+5 kg** in the base, but a brisk creek
needs much more. The fix is a **wide, weighted base plus one stake or tether** —
that turns it into "set-and-forget."

## What it weighs

The model now builds the weight up from components (housing, rotor+shaft+bearings,
generator, battery, electronics), so "how heavy is it?" is computed, not guessed:

| Build | Unit dry | + base ballast | **Total** |
|---|---:|---:|---:|
| 30 cm box, 300 Wh, 0.8 m/s creek | ~10.3 kg | ~2.7 kg | **~12.9 kg (28 lb)** |
| 35 cm box, 500 Wh, 0.8 m/s creek | ~13.6 kg | ~4.5 kg | **~18.1 kg (40 lb)** |

A **40 lb (18 kg) budget is a good fit.** The base build lands near ~28 lb, and
the headroom is best spent on either a **bigger battery** (more buffer / longer
autonomy) or **more base ballast** (stability in a faster creek — heavier is
better there). The heaviest single item is usually the battery, then the housing.

## Shallow water is the binding constraint

The rotor can only be as tall as the water is deep, so **the shallowest spot you
deploy in caps the rotor height — and thus the power.** Because frontal area is
diameter × height, a shallow creek forces a *short, wide* rotor. If you must run
in ~6 in (0.15 m), the rotor is only ~0.12 m tall and power is small unless the
water is fast; the same unit in 2–3 ft makes several times more from the same
diameter. **Deploy in the deepest part of your range you can**, and if you need
laptop-level energy from shallow water, build a little head (see
[BOX_AND_DUCT.md](BOX_AND_DUCT.md)) rather than fighting the depth. Sit the rotor
low with a wide, weighted base so it stays submerged as the creek rises and falls.

## Tough outer shell

The housing drags on gravel and gets knocked by rocks, so make the **outer**
scuff-resistant: an **HDPE/UHMW** shell (kayak/cutting-board plastic), or a printed
**ASA/PCTG** shell with a **truck-bed-liner** coating, plus a bolt-on **UHMW skid
plate** on the base and **TPU corner bumpers** that take the abuse and swap out
cheaply. See [../cad/README.md](../cad/README.md#scuff--abrasion-resistant-outer-shell).

## Two variants

- **Top-stays-dry (recommended, shown above):** outlets live while it runs. Needs
  the creek deep enough to submerge the rotor but not the outlets.
- **Fully submerged, sealed:** the whole box goes under, charges its internal
  battery, and you lift it out to use the outlets. More rugged and hide-able, but
  not "plug-and-play while running," and it's very buoyant if it holds air (see the
  ballast math in [BOX_AND_DUCT.md](BOX_AND_DUCT.md)).

## What's modeled

`creekturbine/selfcontained.py` (tested in `tests/test_selfcontained.py`):

- `SelfContainedUnit` — box geometry → rotor that fits, power, freeboard, min water
  depth
- `drag_force_n` — the current's push on the submerged body (`½·ρ·Cd·A·v²`)
- `hold_mass_for_sliding_kg` / `hold_mass_for_tipping_kg` /
  `required_base_ballast_kg` — how heavy/anchored the base must be
- `estimate_weights` / `weight_breakdown` / `total_weight_kg` — the component
  weight build-up and total, to check against a carry-weight budget

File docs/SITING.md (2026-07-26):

# Siting — measure first, then make the water faster

Because power scales with **velocity cubed**, the two highest-leverage things you
can do cost nothing: **measure honestly**, then **put the rotor where (or make
the water) fastest**.

## 1. Measure your creek (20 minutes, ~$0)

Run `python -m scripts.measure_creek` for the interactive version. The field
procedure:

1. **Pick a reach.** A straight, roughly uniform stretch a few meters long — not
   a still pool, not a waterfall. The best turbine spot is usually the fastest,
   narrowest, shallowest **riffle** you can find.
2. **Width.** Measure the water-surface width (m).
3. **Depth.** Measure depth at several points across the width and **average**
   them (m). Use the average, not the deepest hole.
4. **Velocity — the float method.** Mark two lines a known distance apart (say
   5 m). Drop a floating stick/orange just upstream so it's up to speed, then
   time it between the lines. Average 3–5 runs. Multiply the surface speed by
   **0.85** to get the depth-averaged mean (the surface moves faster than the
   bulk).

Put the three numbers (`CREEK_VELOCITY`, `CREEK_WIDTH`, `CREEK_DEPTH`) into
`creekturbine/config.py`, then run `python -m scripts.size_turbine`.

**Measure in more than one season.** Your rotor and generator should be matched
to **low flow** (so it charges most of the year), while the *frame and anchoring*
must survive **high flow** (spring melt, storms).

## 2. Make the water faster (the v³ lever)

A bare rotor sees the open-channel speed. You can do much better by **speeding
the water up right at the rotor** — and since power ∝ v³, a modest 1.2× speed-up
is a ~1.7× power gain; 1.5× is ~3.4×.

- **Find a natural narrows.** Nature already built chutes — use them.
- **Build a chute / funnel (a "penstock" for kinetic flow).** Funnel the flow
  through a narrower cross-section at the rotor with rock, board, or sandbag
  wing-walls. Conservation of flow (`A₁v₁ = A₂v₂`) means halving the area doubles
  the speed — and in an open channel it accelerates up to the **critical velocity**
  `√(g·depth)` before it chokes and ponds up. This is *the* key move for a
  **mellow, shallow** creek: see **[FUNNEL.md](FUNNEL.md)** and
  `python -m scripts.funnel`. Set `VELOCITY_AUGMENTATION` to the ratio you achieve.
- **Shroud / diffuser.** A duct around the rotor (a "diffuser-augmented" turbine)
  raises throughput; a good one is worth ~1.3–2× but is real engineering.

Don't over-block the natural channel. Backing water up scours the bed, floods
upstream, strands fish, and is exactly what triggers permit trouble. Keep a bare
rotor under ~25–30% of the wetted cross-section (the sizing report checks this),
and always leave a path for water and wildlife around the structure.

## 3. Anchoring, debris, and survival

- **Anchor to both the bed and the bank** so a flood can't walk the turbine
  downstream. Design the frame to be **liftable/removable** before big storms.
- **Trash rack.** Put an angled screen upstream to shed leaves and sticks — a
  clogged rotor makes no power and a jammed one can break. A Savonius shrugs off
  debris far better than a propeller, which is a big reason it's the default.
- **Silt & ice.** Keep bearings above the silt line; plan to pull the unit in a
  hard freeze.

## 4. Permits & neighbors (do this before you build)

Water in a creek is legally not yours to obstruct in most places.

- **Water rights** vary hugely by country/state (riparian vs. prior-appropriation
  in the US). Diverting or obstructing flow can require a permit even for a tiny
  turbine.
- **Environmental rules** protect fish passage, banks, and wetlands. A
  removable, low-blockage, no-dam hydrokinetic unit is the least-intrusive
  option, but **still check** with your local water authority / fish & wildlife
  office first.
- **Talk to downstream neighbors.** Changing flow or clarity, even slightly, is a
  fast way to make enemies. Keep it small, keep it removable, keep it legal.

See **[SAFETY.md](SAFETY.md)** for the electrical and mechanical hazards.

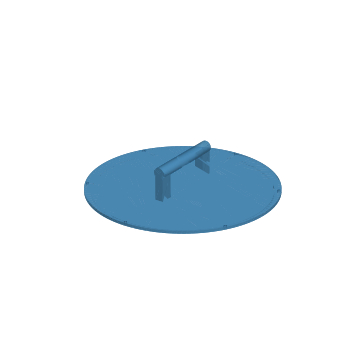
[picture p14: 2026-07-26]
cad/previews/lid_handle.png

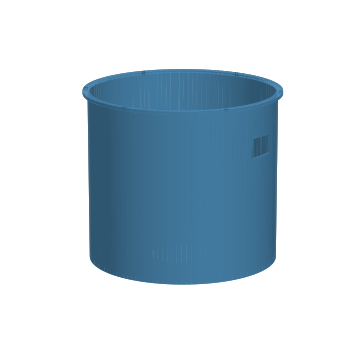
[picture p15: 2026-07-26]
cad/previews/housing_upper.png

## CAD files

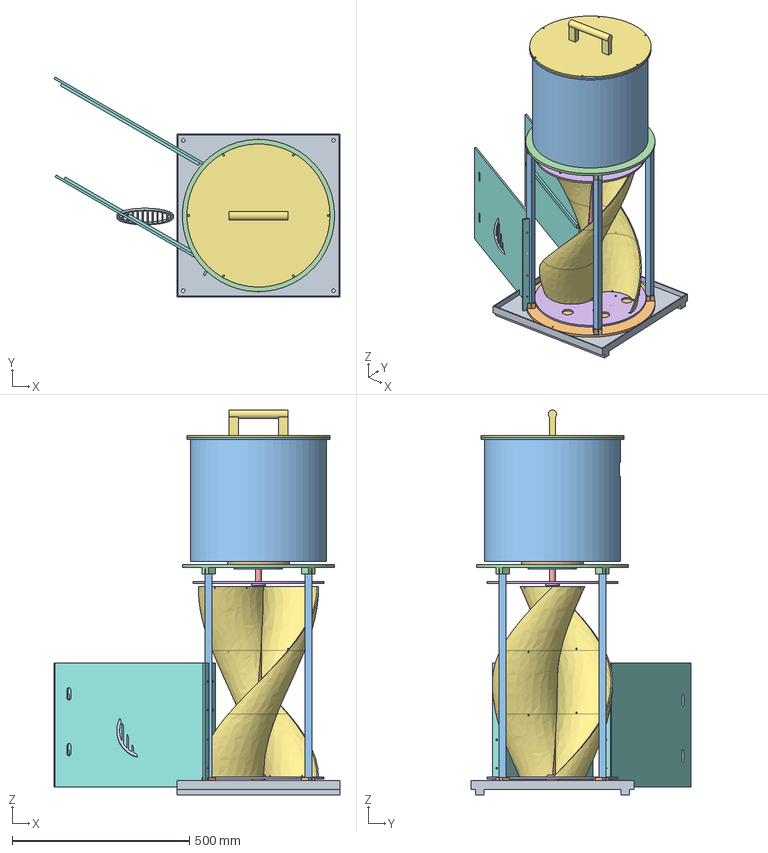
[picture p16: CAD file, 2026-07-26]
cad/step/_assembly.step
807.0 x 621.0 x 1087.0 mm
skid_base
cage_ring_bottom
column_1 (buy: 20mm Al tube) x 4
cage_ring_top
shaft (buy: 16mm stainless)
end_plate_bottom x 2
blade1_seg1 x 6
mag_disc_wet x 2
magnet_cover
bulkhead (cut: 3mm PC sheet)
housing_upper
generator (buy: low-Kv PMA)
generator_mount
battery (buy: 12V LiFePO4)
lid_handle
funnel_wing_L (cut: 6mm HDPE) x 2
trash_rack

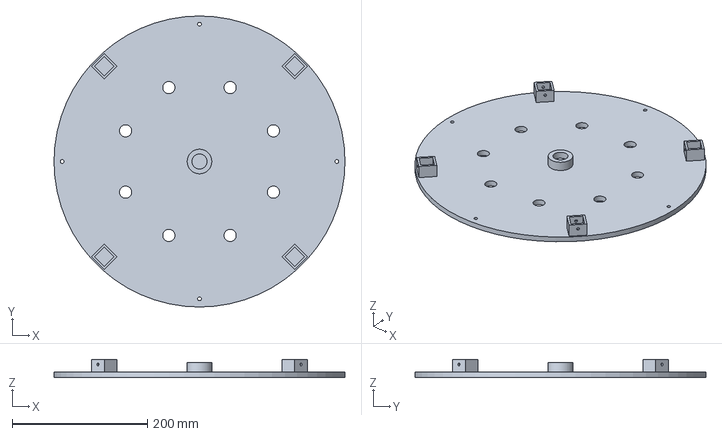
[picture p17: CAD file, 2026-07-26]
cad/step/cage_ring_bottom.step
430.0 x 430.0 x 27.0 mm

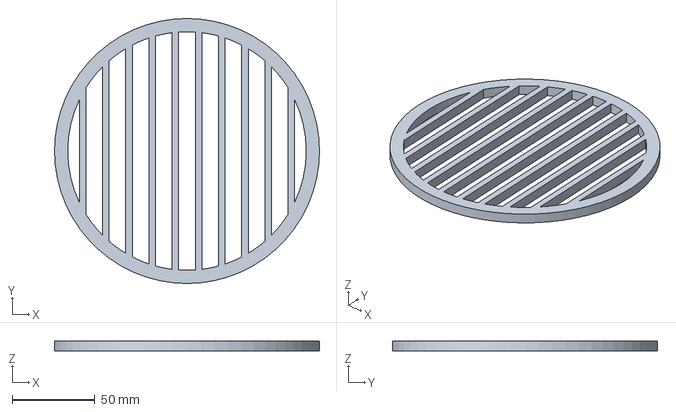
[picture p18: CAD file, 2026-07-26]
cad/step/trash_rack.step
160.0 x 160.0 x 6.00 mm

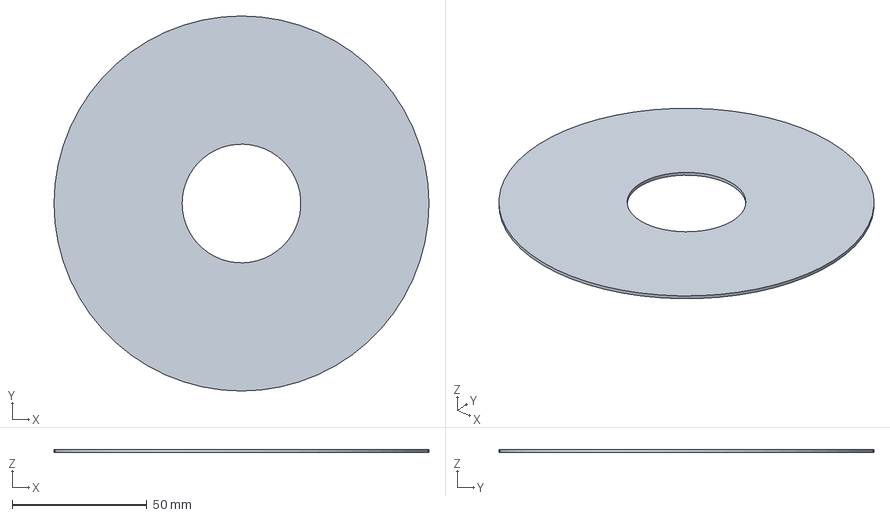
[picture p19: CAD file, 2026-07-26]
cad/step/magnet_cover.step
139.0 x 139.0 x 1.20 mm

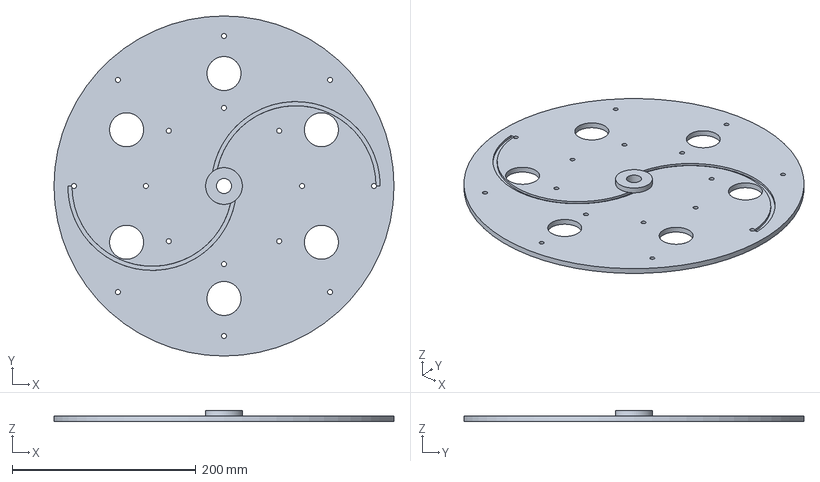
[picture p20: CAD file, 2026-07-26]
cad/step/end_plate.step
370.0 x 370.0 x 12.0 mm

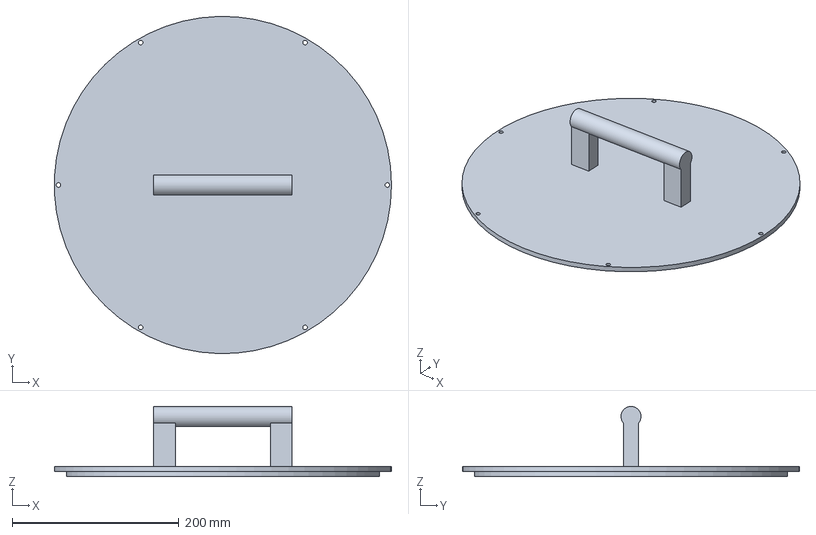
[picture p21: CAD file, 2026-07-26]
cad/step/lid_handle.step
403.7 x 403.9 x 84.0 mm

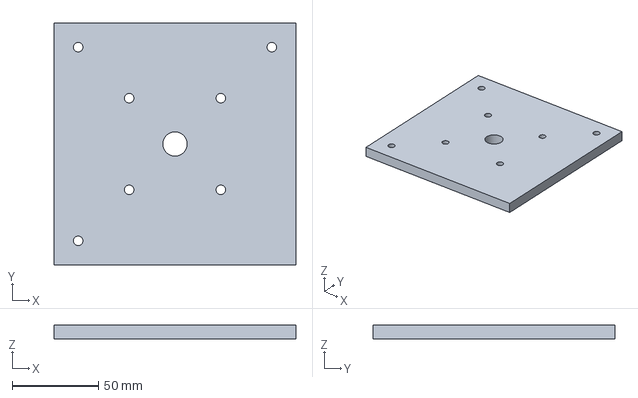
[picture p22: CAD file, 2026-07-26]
cad/step/generator_mount.step
140.0 x 140.0 x 8.00 mm

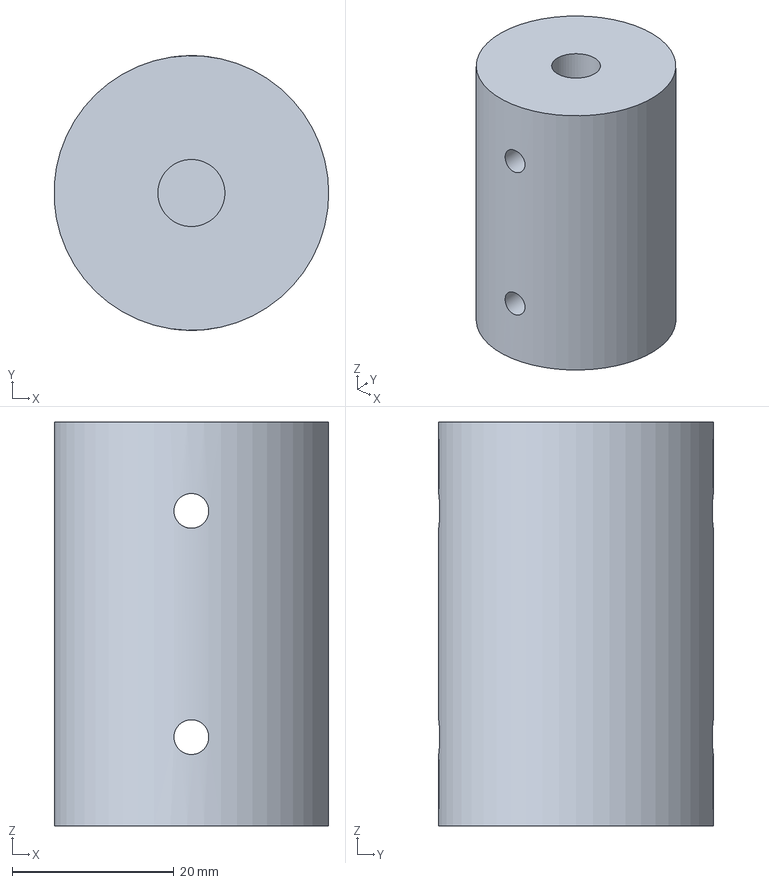
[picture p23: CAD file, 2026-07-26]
cad/step/shaft_coupler.step
34.0 x 34.0 x 50.0 mm

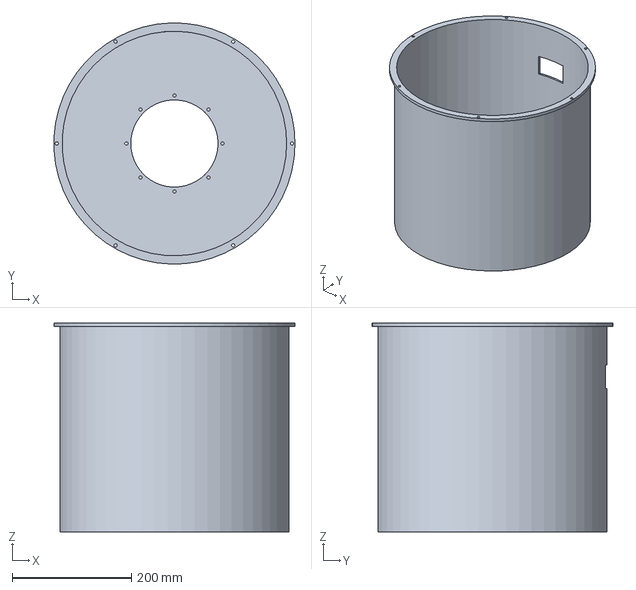
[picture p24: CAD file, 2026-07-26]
cad/step/housing_upper.step
403.7 x 403.8 x 350.0 mm

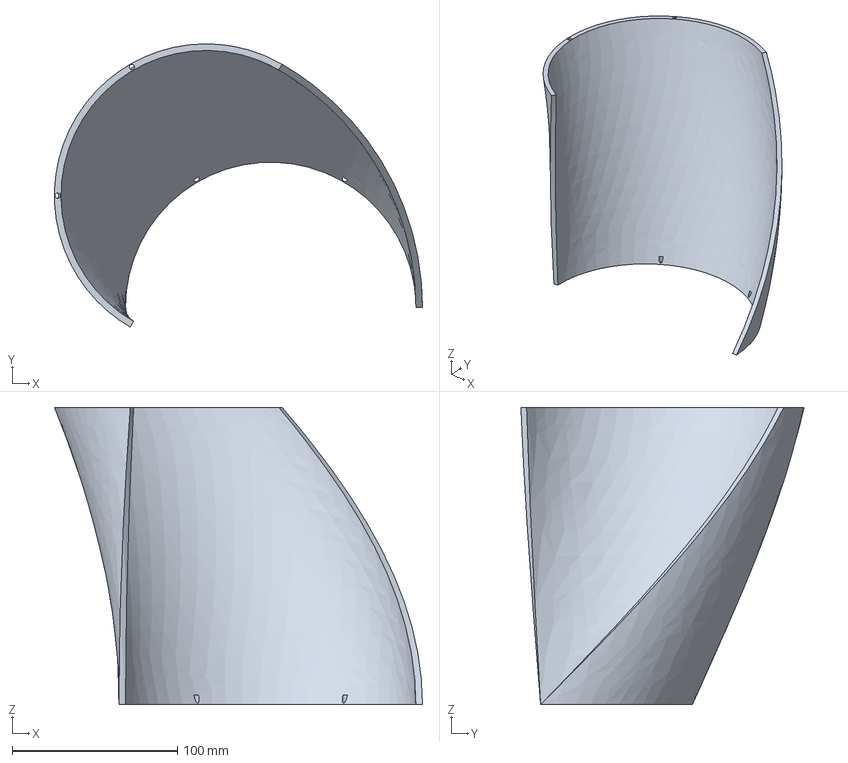
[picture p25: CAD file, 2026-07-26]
cad/step/savonius_blade.step
222.8 x 171.5 x 180.0 mm

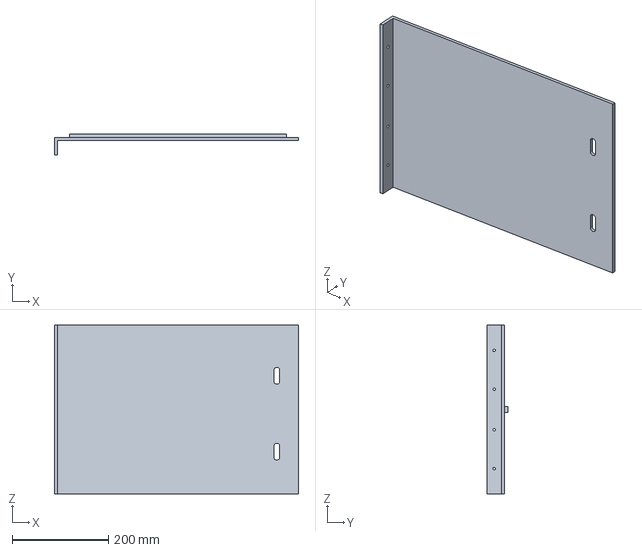
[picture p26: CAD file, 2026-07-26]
cad/step/funnel_wing.step
506.0 x 44.0 x 350.0 mm

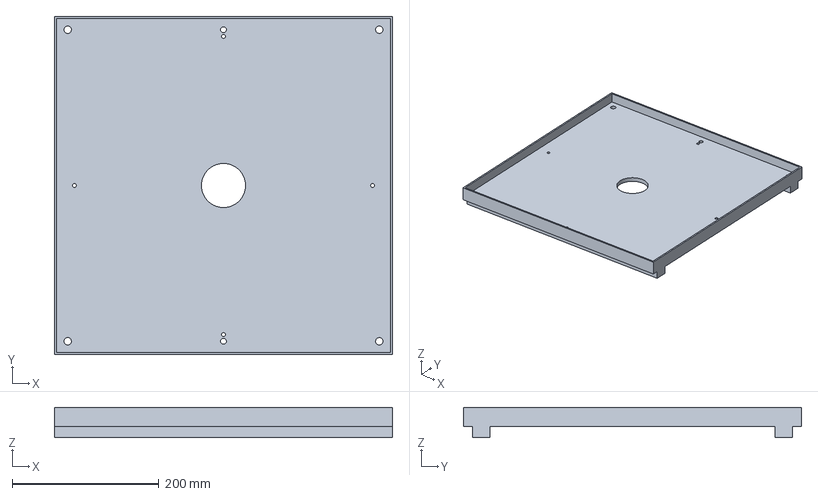
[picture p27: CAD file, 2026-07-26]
cad/step/skid_base.step
460.0 x 460.0 x 41.0 mm

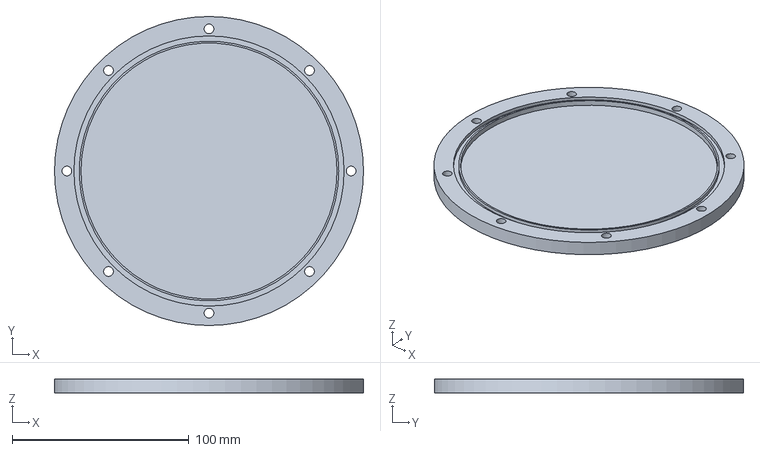
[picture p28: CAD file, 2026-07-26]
cad/step/bulkhead.step
175.0 x 175.0 x 8.00 mm

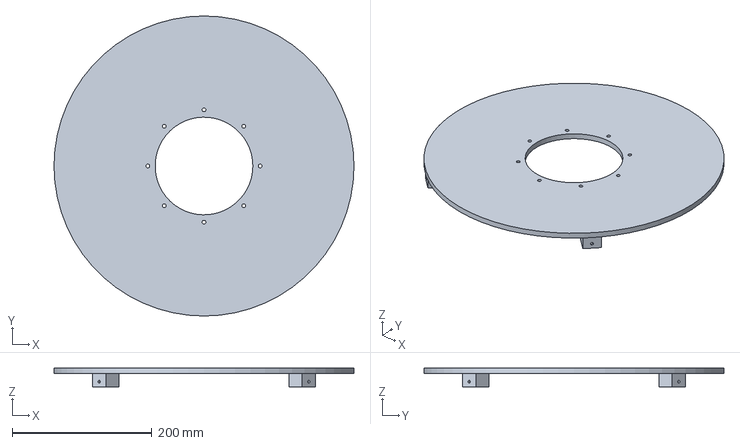
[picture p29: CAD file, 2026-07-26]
cad/step/cage_ring_top.step
430.0 x 430.0 x 27.0 mm

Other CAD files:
cad/step/mag_coupling_disc.step
cad/stl/_assembly.stl
cad/stl/bulkhead.stl
cad/stl/cage_ring_bottom.stl
cad/stl/cage_ring_top.stl
cad/stl/end_plate.stl
cad/stl/funnel_wing.stl
cad/stl/generator_mount.stl
cad/stl/housing_upper.stl
cad/stl/lid_handle.stl
cad/stl/mag_coupling_disc.stl
cad/stl/magnet_cover.stl
cad/stl/savonius_blade.stl
cad/stl/shaft_coupler.stl
cad/stl/skid_base.stl
cad/stl/trash_rack.stl

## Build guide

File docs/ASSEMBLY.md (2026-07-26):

# Assembly guide — from parts to a running creek turbine

This stitches every part and subsystem into a build order. It's written for the
**self-contained unit** (the most complete form — one box, handle on top); the
steps generalize to the drop-in and box-with-head forms too. Do the **planning**
and **bench** phases before you get anywhere near the water.

> ⚠️ Read [SAFETY.md](SAFETY.md) first. A hydro source runs 24/7, can't be
> "switched off," and needs a dump load, a fused battery, and sealed, elevated
> electronics. And settle water rights / fish-passage rules ([SITING.md](SITING.md))
> before you build.

---

## Phase 0 — Plan it in software (free, no parts)

1. **Measure your creek:** `python -m scripts.measure_creek` → velocity, width, depth.
2. **Fill in `creekturbine/config.py`** (the three EDIT-ME blocks). Pick a
   `SAVONIUS_PROFILE` (`optimized` is the sweet spot — see
   [RESEARCH_ROTORS.md](RESEARCH_ROTORS.md)).
3. **Size the rotor & system:** `python -m scripts.size_turbine --figs` → rotor
   diameter/height, expected watts, generator Ke, battery Ah, what it runs.
4. **Size the enclosure & stability:** `python -m scripts.self_contained --figs`
   → box size, freeboard, base ballast, total weight.
5. **Size the sealed coupling:** `python -m scripts.mag_coupling` → magnet count/
   grade/gap for your rotor torque.
6. If chasing more power, model the head option: `python -m scripts.box_turbine`
   ([BOX_AND_DUCT.md](BOX_AND_DUCT.md)).

Copy the resulting dimensions into `cad/params.py`.

## Phase 1 — Make the parts

**3D-print** (`pip install -r requirements-cad.txt && python -m cad.export_all`):

| Part | Qty | Notes |
|---|----:|---|
| `savonius_blade` (helical) | `SCOOP_COUNT` (2) | PETG/ASA, print upright, 4+ walls |
| `end_plate` | 2 | clamp the blades top & bottom |
| `mag_coupling_disc` | 2 | one wet, one dry |
| `bulkhead` | 1 | **non-magnetic material only** |
| `generator_mount` | 1 | carries the PMA in the dry top |
| `shaft_coupler` | 1 | only if not using the magnetic coupling end-to-end |
| `trash_rack` | 1+ | intake screen |

**Buy** (see [HARDWARE.md](HARDWARE.md) BOM): stainless shaft + marine bearings,
low-Kv PMA, NdFeB magnets (~24 for the coupling), 3-phase rectifier, MPPT charge
controller **+ dump load**, LiFePO4 battery + BMS, main fuse, marine wire/
connectors, ballast, fasteners, O-ring, sealed enclosure.

## Phase 2 — Rotor assembly

1. **Stack each blade from its segments**: `BLADE_SEGMENTS` identical printed
   pieces per blade, each rotated by `BLADE_SEG_TWIST`, registered on 3 mm pins
   (filament offcuts) in the end-face holes, joints epoxied.
2. Fit the **shaft** through both `end_plate` hubs (the lower plate carries the
   wet coupling disc).
3. **Seat the blade ends in the plates' profile-matched grooves** (epoxy in the
   groove), phased evenly (2 blades → 180° apart); clock the top plate to the
   blade twist. Run the through-rods/bolts in the plate rings as clamps.
4. Check it spins **true and free** on its bearings before going further.

## Phase 3 — The sealed drivetrain (the clever bit)

1. Press magnets into **both** `mag_coupling_disc` parts in **alternating
   polarity** (N,S,N,S…); the two rings must mirror so N faces S. Epoxy them in.
   **Seal/pot the WET disc's magnets** (bare NdFeB rusts fast). Mind your fingers.
2. Mount the **wet disc** on the rotor shaft (below the bulkhead), the **dry disc**
   on the generator shaft (above it) — **each shaft on a THRUST (or angular-
   contact) bearing**: the discs pull toward each other with ~350–400 N,
   constantly ([MAG_COUPLING.md](MAG_COUPLING.md)). Secure against axial creep
   (collars/circlips) so neither disc can walk into the bulkhead.
3. Clamp the **`bulkhead`** (cut from 3 mm non-magnetic sheet) between them with
   its O-ring, magnets running close on each face. Keep the **gap small** — it
   sets the coupling strength. Confirm the dry side turns when you turn the wet
   side, and that it **slips** cleanly past the design torque.

## Phase 4 — Dry stack (generator + electronics)

1. Bolt the **PMA** to the `generator_mount`, coupled to the dry disc.
2. Wire **PMA → 3-phase rectifier → BOOST-MPPT charge controller → battery**,
   with the **dump/clamp on the generator side, BEFORE the BMS** (a full/cold
   battery opens the BMS — the dump must survive that) and a **fuse at the
   battery +**. Add outputs (USB-C PD module for the laptop / 12 V / a land-side
   inverter).
3. Everything except the generator lives in the **dry, sealed, elevated** part of
   the housing, above the waterline.

## Phase 5 — Housing, intake, ballast

1. Assemble the housing so the **rotor is submerged** and the **outlets stay
   above water** (the freeboard from `self_contained`).
2. Fit the **`trash_rack`** across the intake, angled to shed debris; keep the
   open area generous (the `siting.screen_*` helpers).
3. Add **base ballast** to the computed mass and a **stake/tether** so the current
   can't slide or tip it.

## Phase 6 — Bench test BEFORE the creek

Run **[TEST_PROTOCOL.md](TEST_PROTOCOL.md) tests B1–B5** — each has a procedure,
a pass/fail gate, and a number to record:

- [ ] **B1** generator Ke + real **cut-in** rpm (charging at working rpm)
- [ ] **B2** coupling **slip torque** ≥ 2× operating; axial pull handled
- [ ] **B3** drivetrain **drag torque** < 10 % of operating
- [ ] **B4** dry canister passes the **24 h submersion** (paper-towel test)
- [ ] **B5** controller **idle draw** measured → `CONTROLLER_IDLE_W`
- [ ] Plus: the **dump load** gets warm with a full battery (fill it and check).

## Phase 7 — Wet commissioning

1. Physically **block/lift the rotor** while you place and anchor the unit.
2. Set it so the rotor is submerged, outlets dry; secure ballast + stake.
3. Release the rotor; confirm it **self-starts** and the battery begins charging.
4. Run **[TEST_PROTOCOL.md](TEST_PROTOCOL.md) F1–F4**: site numbers, funnel
   confinement calibration, real Cp, and the **72-hour unattended soak** — the
   unit hasn't graduated to unattended duty until F4 passes.
5. Walk the [SAFETY.md](SAFETY.md) pre-power checklist. Plan to **pull it before
   floods/freezes**.

---

## Where each piece is documented

- Sizing & physics: [ARCHITECTURE.md](ARCHITECTURE.md), [RESEARCH.md](RESEARCH.md)
- Rotor choice: [RESEARCH_ROTORS.md](RESEARCH_ROTORS.md)
- Enclosure forms: [SELF_CONTAINED.md](SELF_CONTAINED.md),
  [PORTABLE.md](PORTABLE.md), [BOX_AND_DUCT.md](BOX_AND_DUCT.md)
- Sealed drivetrain: [MAG_COUPLING.md](MAG_COUPLING.md)
- Parts & printing: [../cad/README.md](../cad/README.md)
- Shopping: [HARDWARE.md](HARDWARE.md) · Plan/phases: [ROADMAP.md](ROADMAP.md)
- Siting, permits, survival: [SITING.md](SITING.md) · Hazards: [SAFETY.md](SAFETY.md)

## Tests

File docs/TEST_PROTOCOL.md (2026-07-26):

# Test protocol — from "modeled" to "trusted"

Every number the toolkit prints is a *prediction*. This protocol is how you turn
predictions into measurements — on the bench first (cheap, dry, reversible),
then in the creek — and **feed each measurement back into `config.py`** so the
model converges on *your* hardware. It closes the open items at the end of
[CRITIQUE.md](CRITIQUE.md).

**Equipment (~$40 beyond the build):** cordless drill with speed control,
multimeter (with 10 A range or a shunt), cheap luggage/fish scale, stopwatch,
tape measure, a floating stick, zip ties, desiccant packs, paper towel.

**Rule for every test:** write the number down (template at the bottom). A test
without a recorded number didn't happen.

---

## Bench tests (do ALL before the creek)

### B1 — Generator curve & cut-in ✻ the most important test
**Why:** cut-in is where DIY builds die (CRITIQUE #1).
1. Chuck the generator shaft (or its coupler) in the drill. Run at 3–4 set
   speeds; measure speed (mark the shaft, count flashes against a stopwatch, or
   use a phone tachometer app) and **open-circuit DC volts** after the rectifier.
2. **Ke = volts ÷ rpm** (it's a straight line — 2 points confirm, 4 points prove).
3. Connect rectifier → controller → battery. Slowly raise rpm until **charge
   current > 0**: that's your real **cut-in rpm**.
4. Convert to water speed: `v_cutin = cut-in rpm ÷ (rpm printed by size_turbine
   per m/s)`. **PASS: v_cutin ≤ your creek's low-season speed.**
5. If using a boost-MPPT: verify it charges with the drill at the rotor's real
   ~40 rpm equivalent. **PASS: charging at working rpm, not just at drill max.**

→ **Feed back:** measured Ke into your generator notes; if cut-in fails, change
the controller (boost) or the pulley ratio — not your hopes.

### B2 — Coupling slip torque & axial pull
**Why:** the τ·A·R estimate must be verified (CRITIQUE open item 4); the axial
force is large (#2).
1. Lock the generator-side disc. Zip-tie a lever (known length L, e.g. 0.3 m) to
   the rotor-side disc. Pull the lever tip with the luggage scale, perpendicular,
   until the coupling **slips**. **Slip torque = scale reading (kg) × 9.81 × L.**
2. **PASS: slip torque ≥ 2× the rotor operating torque** from `size_turbine`
   (default ~2 N·m → need ≥ 4 N·m). Repeat 3×; take the lowest.
3. Axial: with the bulkhead clamped, spin the drivetrain by hand for 5 minutes.
   **PASS: no rubbing sounds, no gap closure, thrust bearings turning freely.**

→ **Feed back:** if slip is low, add magnets / close the gap and re-run
`scripts.mag_coupling`; record the measured vs predicted ratio.

### B3 — Drivetrain drag (the silent power thief)
1. With the generator **disconnected** (open circuit), measure the torque to
   *just keep the drivetrain turning*: lever + scale again, slow steady pull.
2. **PASS: drag torque < 10 % of operating torque** (~0.2 N·m for the default).
   Higher means bearing preload, seal rub, or coupling eccentricity — find it
   now; in the creek it just looks like "less power."

### B4 — Watertightness (the dry canister earns its name)
1. Assemble the dry housing + bulkhead + lid with gaskets, **empty** except a
   paper towel and a desiccant pack taped inside. Weight it and submerge in a
   tub/barrel, deeper than creek depth (≥ 0.5 m of water above the lid).
2. 30 min first, inspect. Then a full **24 h**. **PASS: towel bone-dry twice.**
3. Re-test after every re-opening of the housing. Seals fail on the re-assembly
   you didn't test, not the one you did.

### B5 — Controller idle draw
1. Battery connected, turbine input disconnected, loads off. Measure the DC
   current out of the battery. `P_idle = V × I`.
2. **PASS: ≤ 0.3 W** (25 mA @ 12 V). → **Feed back: `CONTROLLER_IDLE_W`.**

---

## Field tests (in the creek, staged)

### F1 — Site numbers (before anything gets wet)
`python -m scripts.measure_creek` at the actual spot: width, average depth,
float-timed velocity ×0.85. → **Feed back: `CREEK_VELOCITY / WIDTH / DEPTH`.**

### F2 — Funnel confinement calibration ✻ the model's known unknown
**Why:** `confinement = 0.82` is an assumption (CRITIQUE #7).
1. Install the wings + cage, **no rotor yet** (open throat).
2. Float-time the stick through the **throat** over a marked ~1 m, several runs.
3. Compute what the model calls ideal: run `scripts.funnel` with your F1 numbers
   and read `capped_velocity` (or: min(Q/A_throat, √(g·y_throat))).
4. **`confinement = (v_throat_measured − v_ambient) / (v_ideal − v_ambient)`.**
→ **Feed back:** `confinement` in your funnel runs; re-run the sizing. Expect
0.6–0.9; below 0.5 means water is escaping under/around — seal the wing bottoms
to the bed with rocks/sandbags and re-measure.

### F3 — Real rotor Cp (one number that grades the whole rotor)
1. Full unit running, battery charging. Log **battery-side watts** (V × I) over
   ≥ 10 min of steady flow; note the throat velocity (F2 method).
2. **Cp_real = P_elec ÷ (½·ρ·A_rotor·v³ · η_gen · η_drive)** with η_gen from B1's
   curve (or 0.65 default) and η_drive ≈ 0.9.
3. Compare to your selected profile (0.16 / 0.19 / 0.24). **Expect 20–30 % below
   the preset** (lab-vs-field, CRITIQUE #16). → **Feed back: `CP_SAVONIUS` =
   measured, profile = `custom`.** The model now predicts *your* build.

### F4 — 72-hour unattended soak (the graduation exam)
Leave it running three days, visit daily:
- [ ] Net Wh gained per day ≈ model prediction (within the F2/F3-calibrated model)
- [ ] Trash rack shedding, throat clear (note debris per day — sets your
      maintenance interval, CRITIQUE open item 3)
- [ ] No water in the dry canister (towel check), no bearing noise/heat
- [ ] Stakes/ballast unmoved; retrieval line intact
- [ ] Battery not over-full (dump load working) and not draining overnight

**PASS on all five → the unit has earned unattended deployment.** Any failure:
fix, and restart the 72 h clock.

---

## Data log (copy per test session)

| Date | Test | Measured | Model predicted | Ratio | Fed back to |
|---|---|---|---|---|---|
| | B1 Ke (V/rpm) | | | | notes |
| | B1 cut-in (rpm / m/s) | | | | controller/pulley choice |
| | B2 slip torque (N·m) | | ~4.2 | | magnets/gap |
| | B3 drag torque (N·m) | | <0.2 | | bearings/seals |
| | B5 idle draw (W) | | 0.25 | | `CONTROLLER_IDLE_W` |
| | F1 velocity (m/s) | | — | | `CREEK_VELOCITY` |
| | F2 confinement | | 0.82 | | funnel runs |
| | F3 Cp | | profile value | | `CP_SAVONIUS` |
| | F4 net Wh/day | | report value | | sanity |

Two calibration passes (bench, then field) typically bring the model within
~15 % of reality — from there on, `size_turbine` is telling you the truth about
*your* creek and *your* machine.

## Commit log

2026-07-21 Phase 0: honest creek-turbine sizing toolkit (physics, models, CAD, docs)
    A config-driven engineering toolkit that answers "is a hydrokinetic turbine
    worth building for MY creek?" before spending a dollar — no hardware required.
    Core package (creekturbine/):
    - hydrokinetics.py: P = ½·ρ·A·v³, Betz limit, rotor sizing, rpm/torque,
    flow augmentation — the physics, tested against hand-computed values
    - rotor.py: Savonius (recommended) + axial rotors behind one interface;
    sizing helpers turn a power target into rotor dimensions
    - generator.py: cut-in velocity + Ke matching (the classic DIY failure point)
    - energy.py: daily/annual Wh, battery Ah sizing, "what it runs" table
    - siting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
    [end_plate.step, end_plate.stl, generator_mount.step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]
2026-07-21 Add ducted / low-head "enclosed underwater box" model
    Answers the design question "can I have an air-filled underwater box, dry
    inside, that routes water past a turbine?" with real numbers.
    - creekturbine/ducted.py: velocity_head (why a creek's speed is worth ~3 cm of
    head), low_head_power (ρgQHη), throat_velocity (Torricelli + losses), a
    DuctedBox dataclass (throat area / static head / diffuser gain -> flow &
    power), and buoyancy_force/ballast_mass for a submerged air box.
    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
2026-07-21 Add portable "power-station" model (carry-anywhere creek unit)
    Answers "can this be portable for any creek, with a waterproof cable to shore,
    a battery, and source-switching?" — yes: a battery-buffered hydro power station.
    - creekturbine/portable.py: battery-buffer math (runtime, sustained vs burst,
    recharge), cable volt-drop + minimum conductor sizing (shows why a long run
    wants a higher bus voltage — ~16x less copper 12V->48V), pack-weight budget,
    and a PortableUnit report tying creek speed + rotor + battery + cable together.
    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
2026-07-21 Add self-contained all-in-one unit model ("box with a handle")
    Models the plug-and-play form the user wants: one carriable housing set in the
    creek, rotor at the bottom (wet), generator + battery + outlets stacked above
    the waterline (dry), handle on top. No cable, no shore box.
    - creekturbine/selfcontained.py: SelfContainedUnit (box geometry -> rotor that
    fits, power, freeboard, min water depth) plus the stability math that's the
    real catch of a free-standing box: drag_force_n (½ρCdAv²) and the sliding /
    tipping ballast needed so the current can't move it.
    - simulator.py: self_contained_schematic() side-view (rotor wet, dry stack,
    waterline, flow, and the sizing/stability number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
2026-07-21 Compute self-contained unit weight from components (40 lb budget check)
    Weight was an assumed input; now it's built up from parts so "how much does it
    weigh?" is answered with real numbers.
    - selfcontained.py: estimate_weights() component build-up (housing from surface
    area, battery from Wh, rotor/shaft/generator/electronics), a dry_mass_kg
    property (computed unless overridden), weight_breakdown(), and total_weight_kg
    (dry + required base ballast). required_base_ballast_kg now uses the computed
    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
2026-07-22 Rotor-geometry research + execute: profiles, helical blade CAD, cited doc
    Adds a cited, adversarially-verified survey of high-Cp + durable hydrokinetic
    rotor geometries and bakes the findings into the toolkit and CAD.
    Research:
    - docs/RESEARCH_ROTORS.md: synthesis of a multi-source deep-research pass (12
    claims confirmed by 3-vote adversarial verification, 1 refuted, frontier /
    durability items flagged unverified where the run hit a usage limit). Covers
    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
    [savonius_blade.step, savonius_blade.stl]
2026-07-22 Firm up rotor research: full verification (22 confirmed, 3 refuted)
    Re-ran the deep-research verification after the usage limit reset — all 105
    agents completed (0 errors), upgrading the frontier/durability claims from
    "unverified" to verified and producing a proper merged synthesis.
    Updates to docs/RESEARCH_ROTORS.md:
    - 25 claims verified (3 votes each) -> 22 confirmed, 3 refuted, 0 unverified.
    - Frontier (VIV/VIVACE/galloping/WIV, flapping foils) now CONFIRMED but caveated:
    real low-speed onset (to 0.2 m/s) yet tiny net power (v^3), CFD-stage, moving
    parts -> "watch, don't build." One FIV sub-claim refuted.
    - Durability CONFIRMED and reframed: sediment abrasion/debris/fatigue/foulin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
2026-07-22 Add sealed magnetic coupling (model + CAD) — no shaft seal to leak
    The wet turbine shaft drives the dry generator through a solid bulkhead via two
    magnet discs — the wet→dry crossing the box/self-contained designs depend on.
    Overload just makes the magnets slip (built-in torque limiter).
    - creekturbine/magnetics.py: axial-coupling torque model (T ≈ τ·A·R with τ from
    B_gap²/2μ0 and a gap derating), AxialMagCoupling dataclass (max_torque/holds),
    and magnets_needed() to size the magnet count to the rotor torque + margin.
    - scripts/mag_coupling.py: pulls the rotor's operating torque from config and
    prints a buildable design (default ~2 N·m rotor -> 12 x Ø15x6 N42 per disc,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
    [mag_coupling_disc.step, mag_coupling_disc.stl]
2026-07-22 Complete the build: bulkhead + trash rack CAD, screen model, assembly guide
    Finishes the physical part set and stitches everything into a build order.
    - cad/bulkhead: the non-magnetic sealing plate the magnetic coupling drives
    through — thin center membrane (part of the coupling gap) + bolted, O-ring-
    grooved rim. Print in polycarbonate/fiberglass/aluminium, never plain steel.
    - cad/trash_rack: barred intake screen that sheds debris (the #1 field failure
    the rotor research flagged); rim + parallel bars.
    - siting.py: screen_open_ratio / screen_approach_velocity so the rack's open
    area is sized (too little = head loss; too much face velocity = pins debris),
    with an honest note tha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
    [bulkhead.step, bulkhead.stl, end_plate.step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]
2026-07-22 Add scuff-resistant outer spec + laptop-charge load; depth-power note
    Captures the stated build requirements:
    - Scuff/abrasion-resistant outer shell guidance (HDPE/UHMW shell, or ASA/PCTG +
    truck-bed-liner coat, plus a sacrificial UHMW skid plate and TPU corner
    bumpers) in cad/README, SELF_CONTAINED, and the HARDWARE portable BOM.
    - energy.py: explicit "Laptop charge (1/day)" ~70 Wh load (vs running it active),
    so "what it runs" shows laptop charging directly.
    - SELF_CONTAINED: "shallow water is the binding constraint" note — the shallowest
    deploy depth caps rotor height and thus power; deploy deep or add head for
    laptop-level energy from 6-inch water.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
2026-07-22 Add funnel (converging-intake) model — make a mellow, shallow creek useful
    Explores the funnel idea: wall the creek into a converging chute so the flow
    speeds up at the rotor. Key physics captured:
    - continuity (A1v1=A2v2) reframed as P = ½ρ·Q·v² — the funnel routes the creek's
    whole flow rate Q through the rotor, so a lazy-but-decent-flow creek becomes
    useful once v is raised;
    - the honest open-channel ceiling: critical velocity √(g·depth) (~1.2 m/s at 6
    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
2026-07-23 Universal free-standing funnel unit — works in any creek ≥4 ft wide
    Reframes the funnel from a site-specific bank-to-bank weir to a portable unit
    with a FIXED gather mouth that drops into any creek wider than it, with the honest
    physics cost of that portability.
    - funnel.py: `confinement` factor (1.0 = walled weir realizes the full choke-to-
    critical speed-up; ~0.82 free-standing, since open bypass lets gathered flow
    spill around it) and a `FunnelIntake.universal()` builder with a fixed gather
    width and a throat capped to the water depth. +2 tests (107 total pass).
    - scripts/funnel.py: `--universal` depth-sweep mode (fixed 0.9 m / ~3 ft gather →
    fits creeks >~4 ft) showing pow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
2026-07-23 Red-team audit: 18 findings, systematic fixes across power/CAD/flood/docs
    Adds docs/CRITIQUE.md — a severity-ranked audit of the whole design with every
    finding tracked to a resolution — and implements the fixes.
    Critical (would have stopped the build):
    - Generator Ke recommendation was unbuyable (0.3-1.0 V/rpm vs ~0.15 market max).
    generator.practical_options() reality-checks it; size_turbine now prescribes a
    BOOST-type MPPT (charges 12 V from a few volts, the modern slow-rotor fix) or
    a ~4:1 belt step-up. BOM updated.
    - Magnetic coupling axial pull was unmodeled: AxialMagCoupling.axial_force_n()
    shows ~380 N constant disc-to-disc attraction; script + docs now demand thrust
    b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
    [bulkhead.step, end_plate.step, end_plate.stl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]
2026-07-23 CAD the complete unit: 7 new parts, one dimensional chain, assembly render
    The whole machine is now modeled — 14 parametric parts on a single dimensional
    chain (blade -> end plate -> housing bore -> cage -> skid): change ROTOR_DIA /
    ROTOR_HEIGHT and everything re-derives.
    New parts (cad/parts/):
    - cage_ring_top / cage_ring_bottom: the open wet cage — printed rings socketing
    4 BOUGHT 20 mm aluminium square-tube columns (600 mm one-piece is unprintable;
    tube is stiffer). Top ring shares the 8-bolt clamp stack (cage -> bulkhead ->
    housing floor); bottom disc has a raised lower-bearing boss (silt must climb),
    drain holes, and the skid bolt circle.
    - housing_upper: the dry canister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
    [bulkhead.step, bulkhead.stl, cage_ring_bottom.step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]
2026-07-23 Add TEST_PROTOCOL.md: bench + field tests that calibrate the model
    Turns CRITIQUE.md's open items into concrete procedures with pass/fail gates
    and an explicit feed-measurements-back-into-config loop:
    Bench (B1-B5): generator Ke curve + real cut-in rpm (the make-or-break test),
    coupling slip torque via lever + luggage scale (vs the ~4.2 N·m prediction) and
    axial-pull check, drivetrain drag torque (<10% of operating), 24 h submersion
    watertightness (paper-towel test, re-test after every re-opening), controller
    idle draw -> CONTROLLER_IDLE_W.
    Field (F1-F4): site measurement, funnel confinement calibration (float-timed
    throat velocity -> replaces the 0.82 assumption), real rotor Cp from logg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
2026-07-24 Mk1 design freeze + positioned base CAD assembly (portfolio-ready)
    - docs/SPEC.md: the canonical frozen specification — 17 locked design decisions
    (D1-D17) each with rationale links, the performance envelope, key mechanical
    interfaces (clamp stack, shaft, columns, bolts), carry weight (~15 kg dry;
    ballast = creek rocks added on-site), cost band, and the short explicit list
    of parameters deliberately left to prototype calibration (TEST_PROTOCOL refs).
    - cad/assembly.py: builds the positioned full-unit assembly (28 named parts,
    including bought items — Al columns, shaft, PMA, battery — as labeled solids)
    and exports cad/step/_assembly.step (opens in any CAD tool, parts named)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
    [_assembly.step, _assembly.stl]
